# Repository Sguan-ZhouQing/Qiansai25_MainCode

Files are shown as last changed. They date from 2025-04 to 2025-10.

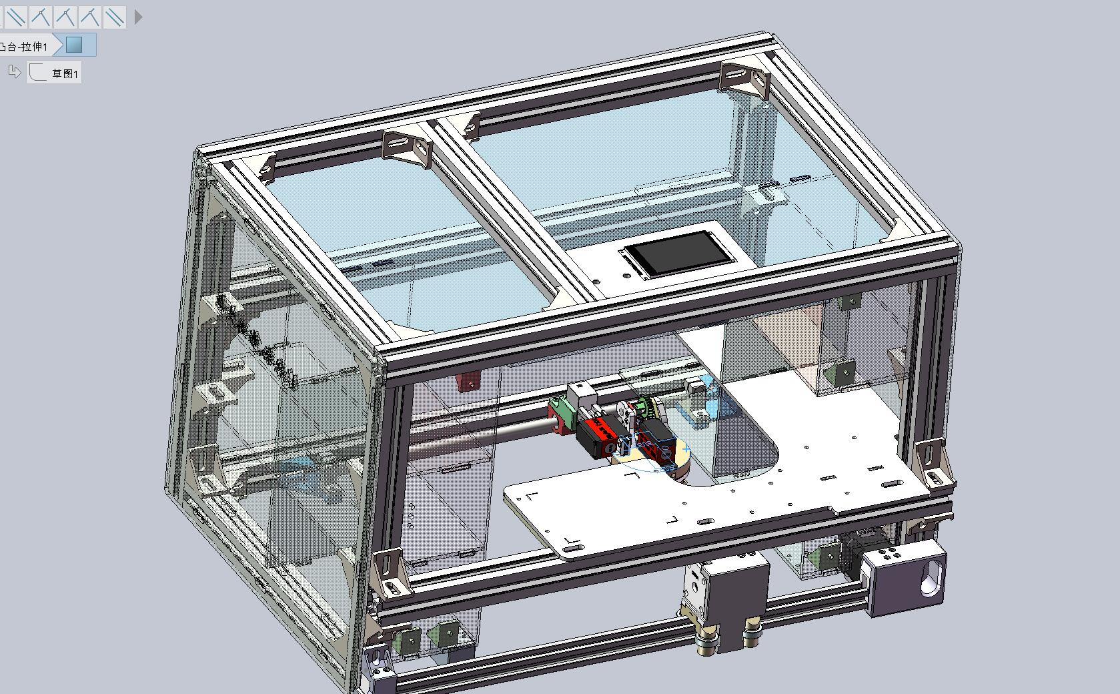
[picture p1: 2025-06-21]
药仓实况照片.jpg

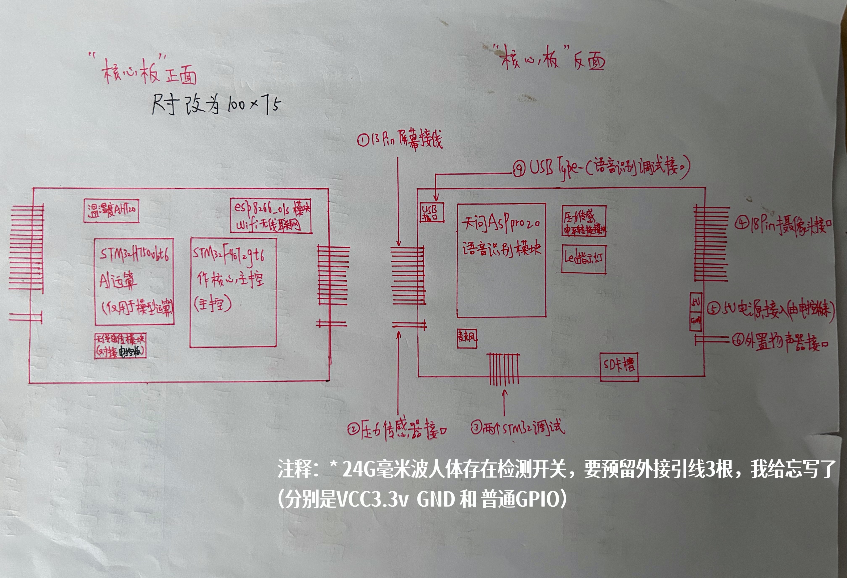
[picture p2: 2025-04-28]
电路篇/核心板PCB大纲.JPG

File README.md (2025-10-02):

# Qiansai25_MainCode
An integrated intelligent pharmacy warehouse that integrates medication management.集用药管理平台的一体化药仓

[![zread](https://img.shields.io/badge/Ask_Zread-_.svg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)](https://zread.ai/Sguan-ZhouQing/Qiansai25_MainCode)
https://zread.ai/Sguan-ZhouQing/Qiansai25_MainCode

QQ截图20250622031556

主控采用STM32F407vgt6，

运算使用STM32H750vbt6，

电控使用的是芯片是STM32G431cbt6！

This project designed an integrated intelligent medicine warehouse for personal home use and hospital commercialization. The main functions of this medicine warehouse include intelligent visual recognition, custom storage and automatic drug pick-up, automatic human body induction switching power supply, adjustable medication and drug pick-up time reminder, independent drug contraindication reminder, medication calendar recording and analysis, cloud platform data storage...... For long-term drug users or those who have more drug storage needs, the use of the integrated medicine warehouse of this project can greatly reduce the time of drug search, and can know the health index of their long-term medication in real time. The main control of the drug warehouse designed in this project uses the STM32H7 series of high-performance microprocessors for the calculation of the "lightweight AI model", and feeds back the analyzed medication information to the main control STM32F407 for processing. The main control is separated from the motor that actually drives the drug dispensing mechanism, and its operation is controlled by wireless transparent transmission. In addition, we have also developed a "embedded GUI interface" and a "mobile phone APP" suitable for the use of medicine warehouses, and we have also developed medicine warehouses to store user data for the cloud platform and share it with other devices.

本项目设计了一款面向个人家用和医院商用的**一体化智能药仓**，旨在通过智能化技术解决药品管理中的痛点问题。系统以STM32H7系列高性能微处理器为核心，搭载轻量化AI视觉识别模型，可自动识别药品的形态、颜色和包装特征，实现药品的智能分类与入库管理。同时，主控STM32F407负责协调药仓的机电控制系统，通过无线透传模块与执行机构通信，实现药品的精准抓取和配送。

药仓配备多模态传感器阵列，包括红外人体感应模块、重量检测单元和环境监测传感器，可智能感知用户接近自动唤醒系统，并实时监控药品存储环境（温湿度、光照等）。创新设计的**服药智能提醒系统**支持自定义服药时间设置，通过语音播报、LED指示灯和手机APP推送三重提醒方式，确保用户按时服药。系统还能基于药品数据库自动分析药物配伍禁忌，在取药时提供安全警示。

为提升用户体验，我们开发了**嵌入式图形化操作界面**，采用触控屏实现交互，支持药品信息查询、服药记录查看等功能。配套的**跨平台手机APP**（支持iOS/Android）允许用户远程管理药仓、设置服药计划，并生成可视化的服药健康报告。所有数据通过MQTT协议同步至OneNET云平台，实现多设备间的数据共享和长期健康趋势分析，为慢性病患者和家庭医生提供决策支持。

在机械结构方面，药仓采用模块化设计，抽屉式药格可根据药品尺寸灵活调整，伺服电机驱动的机械臂配合高精度导轨实现药品的平稳取放。系统还预留了扩展接口，可兼容医院HIS系统或智能家居平台，满足家庭医疗和机构场景的不同需求。通过这一创新设计，我们期望能显著提升长期服药患者的用药依从性，减少人为用药错误，并为智慧医疗和健康管理提供可靠的硬件支持。

This project designs an integrated intelligent medicine warehouse for personal household and hospital commercialization, aiming to solve the pain points in drug management through intelligent technology. The system is based on the STM32H7 series of high-performance microprocessors and is equipped with a lightweight AI visual recognition model, which can automatically identify the shape, color and packaging characteristics of drugs, and realize the intelligent classification and storage management of drugs. At the same time, the main control STM32F407 is responsible for coordinating the electromechanical control system of the medicine warehouse, and communicates with the actuator through the wireless transparent transmission module to achieve accurate grasping and distribution of drugs.

The pharmacy warehouse is equipped with a multi-modal sensor array, including an infrared human body sensing module, a weight detection unit and an environmental monitoring sensor, which can intelligently perceive the automatic wake-up system when the user is approaching, and monitor the drug storage environment (temperature, humidity, light, etc.) in real time. The innovatively designed intelligent medication reminder system supports custom medication time settings, and ensures that users take their medication on time through voice broadcasting, LED indicators and mobile APP push triple reminders. The system can also automatically analyze drug compatibility contraindications based on the drug database, and provide safety warnings when taking drugs.

In order to improve the user experience, we have developed an embedded graphical operation interface, which uses a touch screen to achieve interaction, and supports functions such as drug information query and medication record viewing. The companion cross-platform mobile app (iOS/Android supported) allows users to remotely manage the pharmacy, set up medication schedules, and generate visual medication health reports. All data is synchronized to the OneNET cloud platform through the MQTT protocol to achieve data sharing and long-term health trend analysis between multiple devices, and provide decision-making support for patients with chronic diseases and family doctors.

In terms of mechanical structure, the medicine warehouse adopts a modular design, the drawer-type medicine compartment can be flexibly adjusted according to the size of the drug, and the robotic arm driven by the servo motor cooperates with the high-precision guide rail to achieve smooth access and placement of drugs. The system also reserves an expansion interface, which can be compatible with hospital HIS system or smart home platform to meet the different needs of home medical and institutional scenarios. Through this innovative design, we expect to significantly improve medication compliance for patients taking long-term medications, reduce human medication errors, and provide reliable hardware support for smart healthcare and health management.

集用药管理平台的一体化智能药仓
STorm小分队；周庆；薛琬莹；钱一程；刘勇
摘要	
本作品“集用药管理平台的一体化智能药仓”基于机电一体化硬件、AI中枢与云端协同网络，实现了药品存储、管理与配送的智能化解决方案。系统以STM32H7高性能处理器为核心，搭载轻量化AI视觉识别模型，结合STM32F407主控与STM32G431电控板，通过多模态传感器（红外对射、压力传感器等）实现药品的精准抓取和配送。机械结构采用模块化分隔设计，支持灵活调整以适应医院药房和家庭健康监护场景。
功能上，系统具备实时环境监控、用户接近感知自动唤醒、多模式服药提醒（语音、LED、APP推送）、药品配伍禁忌分析及嵌入式触控交互界面。配套跨平台手机APP（iOS/Android）支持远程管理，数据通过MQTT协议同步至OneNET云平台，实现多设备协同。
技术层面，项目融合Uinapp、FreeRTOS、STM32CubeAI及LVGL图形化GUI，采用多核异构架构与分布式控制，结合无线/有线通信方式，确保高效稳定的运行。简化传统药物存储流程，降低人力成本；通过智能化管理提升用药安全性与便捷性；模块化设计增强系统扩展性。最终成果通过严格的测试验证，满足药物抓取精度、云端部署等性能指标，为医疗健康领域提供了高效、可靠的物联网应用范例。

第一部分  作品概述
1.1	功能与特性
实现药品的精准抓取和配送，实时监控药品存储环境，智能感知用户接近自动唤醒，服药智能提醒系统可自定义服药时间，通过语音播报、LED指示灯和手机APP推送等提醒方式；系统基于药品数据库自动分析药物配伍禁忌，在取药时提供安全警示；嵌入式图形化操作界面采用触控屏实现交互，提升面向对象的使用体验。
1.2	应用领域
本系统为医疗机构和家庭用药场景提供智能化管理解决方案。在医疗领域，系统通过自动化药品抓取配送、配伍禁忌分析和环境监测三大功能，有效解决传统药房人工管理效率低、易出错的问题…可集成至医院智能药房，实现药品的精准分类、库存实时监控及快速取药。智能化的药品分类与库存监控配合云端数据同步，使管理人员可实时掌握药品信息，优化资源配置。
针对家庭用药场景，系统通过多模式提醒、触控交互和近场感应技术，为老年人和慢性病患者提供便捷的用药管理服务。家庭成员可通过专属APP实现远程监护，确保用药安全。系统兼具专业性与易用性，提供无障碍体验,显著提升医疗和家庭场景的用药管理效率。
1.3	主要技术特点
本系统基于Uinapp框架构建跨平台移动应用，实现iOS/Android双端兼容的用户交互界面，通过FreeRTOS实时操作系统对多任务进行高效调度，确保系统响应实时性。利用STM32Cube.AI工具链部署轻量化AI模型至嵌入式端，实现本地化药品识别与配伍分析，显著降低云端依赖。系统采用LVGL图形化GUI框架开发触控交互界面，优化人机交互体验，同时集成Wi-Fi、蓝牙、I2C、SPI、CAN等多种通信方式，构建灵活可靠的数据传输网络，支持设备间协同与云端数据同步。这一技术架构在保证系统实时性能的同时，实现了实时计算到云端协同的完整解决方案。
1.4	主要性能指标
图像识别准确率，IOT联网成功率，机械臂能够稳定抓取药品的容错率。

1.5	主要创新点
1.	解决了传统药物存储和分类的繁琐流程，简化了人力物力支出。方便药品后期管理和实时用药取药，有效解决传统药房人工管理效率低、易出错的问题。
2.	机械结构采用可快速重构的模块化方案，同一平台可适配医院药房和家庭用药两种差异化的应用场景。
3.	创新性地在边缘设备部署轻量化AI模型，同时通过MQTT协议实现云端数据同步，在保证响应速度的同时实现了多终端数据共享。
4.	结合毫米波接近感应和语音交互技术，为老年用户提供了更人性化的无接触操作体验。
1.6	设计流程
 
本项目遵循系统化的设计开发流程，从项目方案的技术定型阶段开始，工程团队首先完成核心机器架构的详细设计，并实现关键支撑结构的组装验证。随后进入硬件工程实施阶段，涵盖机械结构设计、多层PCB电路板的精密印刷与焊接工艺、机电一体化装配，以及严格的电路功能测试和系统安装方案优化。在软件层面，项目团队同步开展模块化驱动开发工作，在完成底层驱动开发后，团队构建了完整的应用层业务逻辑，同时推进云端服务架构设计，采用OneNET云平台在阿里云环境实现高可用部署。项目最终经过严格的系统级测试验证，包括功能测试、性能测试和稳定性测试，确保整体系统达到设计指标。

第二部分  系统组成及功能说明
2.1	整体介绍
 
智能药仓集成机电一体化硬件与AI技术，核心采用STM32系列处理器（H7/F407/G431）协调控制，搭载轻量化AI视觉识别模型和多模态传感器阵列，实现药品精准抓取、环境监测及用户感知。系统支持模块化药仓设计，具备智能服药提醒（语音/LED/APP推送）、药物配伍禁忌警示及触控屏交互功能，配套跨平台APP支持远程管理，通过MQTT协议与云端同步数据，满足医院药房和家庭场景的智能化药品管理需求。
2.2	硬件系统介绍
2.2.1 硬件整体介绍；
本系统以STM32H7高性能处理器作为核心运算单元，运行轻量化AI视觉识别算法实现药品智能识别。系统主控采用STM32F407微控制器，协调药仓机电控制系统，与分布式控制单元（基于STM32G431的电控板）实时交互。各执行器单元集成高精度红外对射传感器和应变式压力传感器，实现药品抓取定位和配送。
2.2.2 机械设计介绍
 机械结构设计采用30-30铝型材搭建药仓整体的骨骼框架，并在多处使用了高透或乳白色亚克力板。整个项目药品的抓取和拿放都依靠其中5个270度舵机组成的简易机械臂和XY轴步进电机驱动系统。项目实物多处使用到了M4和M6公制螺丝进行加固，并在设计到实物的过程中，普遍采用到了3D打印技术去完成本项目的实物制作需求。
	在此一体化智能药仓项目在实物搭建上，使用到了亚克力玻璃板将药仓空间划分为12个单独的储存仓室，并准备为每一个仓室适配各自的夹取药品的机械运动轨迹…实现药物精准配送。
 	 
	对于机械臂的设计，我们使用到了5个20N·cm的270度舵机，并依次连接组合成了一个5个自由度的机械抓取机构。同时，机械臂底部B轴与XY轴步进驱动系统相连，可以让整体机械臂在药仓的运动范围不受太大限制，实现药物配送任务的快速完成。详细到机械臂末端抓取机构，本团队成员使用到了舵机链接“双人字齿轮”，驱动平行对称的连杆机构，进而达到抓取药品有较平稳的夹取姿态。
在机械爪末端预留了槽位用于“红外对射传感器”和“薄膜压力传感器”的安装。它的作用是检测夹取药品时，判断当前位置是否真有药品可以用于夹取，并在夹取过程中通过压力传感器得到力度合适的舵机运动角度。
	 
本项目药仓还在实物顶部设计了“可容纳摄像头模组和触控屏”的非标机械设计，可用于后期做药品的图像采集和图像识别…从而完善整个工程从药品入库到配送这一流程链的智能和自动化的属性。
 
	在亚克力板设计上，项目也有为后期电路PCB板的安装上的思虑。团队成员为所有可能安装电路板和电线走线的地方都有一定安装余留和孔位预留。这为为后期电路搭建建立了良好的容错空间。

2.2.3 电路各模块介绍
 
本项目的电路驱动系统采用到了3块ST公司主流的MCU产品，他们分别是用于主控的STM32F407VGT6，用于做电机控制的STM32G431CBT6和可部署“STM32cube.AI工具链”用于做药仓的药品入库图像识别。其中，用于主控和图像识别的MCU，我们使用到了自绘的“洞洞板”连接各个模块的功能引脚…而对于电机控制的电控板，我们自制了完整的电路开发板，其PCB设计界面及原理图如下：

2.3	软件系统介绍
2.3.1 软件整体介绍（含PC端或云端，结合关键图片）；
软件上本项目采用到了GUI_Guider软件设计LVGL图形化GUI界面，完美适配STM32端单片机的屏幕软件触控交互。团队成员也同时开发了网页端和APP端的上位机控制控制软件，实现药仓万物互联…可以通过分享账号，让家人或者管理人员远程操控药仓的入库及配药。
   
2.3.2 软件各模块介绍
	上位机APP和云端代码由我们团队成员使用Vue.js和HBuilderX自主开发完成。Vue.js是一个用于构建用户界面的渐进式 JavaScript 框架,也是当前的最流行的前端开发框架之一。Vue.js的双向数据绑定机制，很好的支持了我们APP和云端网站的数据动态更新及交互。此外，我们使用HBuilderX将Vue.js代码打包成apk安装包和web包，使Vue.js代码既可在移动端应用，也可在PC端部署，丰富了项目的软件生态。
上位机APP与云端网站通过HTTP请求，以OneNet平台为媒介实现与硬件之间的通信。
 
图为APP读取硬件设备数据

图为APP下发命令控制硬件设备

	 APP主要页面包括：首页（导航页面）、存药页面、取药页面、药仓药品实时情况页面等。登陆页面密码固定为：123456。
 
APP结构图
可视化图表为用户提供清晰明了的药仓数据，其中涉及到的主要代码逻辑为：封装自定义组件CircleChart、从 OneNet平台获取数据、对数据进行处理、使用自定义组件CircleChart进行图表绘制。
用户可通过APP查询药仓实时情况，实现异地查询药仓药品情况，打破空间限制。用户仅需在药仓实时情况页面点击“获取药仓药品信息”按钮，即可获取最新信息。Vue.js的双向数据绑定机制支持动态更新数据，用户可以随时获取最新信息。
  
图为获取最新药品信息操作流程
我们还使用HBuilderX将uniapp项目打包成web代码，并通过宝塔面板将其部署到阿里云服务器上。使用者不仅可以下载APP，还可以通过访问我们的网站来实现对药仓的操控或查询药仓药品。虽然移动端APP使用起来十分便利。但是云端网站仍然具有不占手机内存，不限制手机操作系统（安卓和苹果均可在浏览器输入网址访问我们的网站）等优点。 

第三部分  完成情况及性能参数
阐述最终实现的成果（图文结合，实物照片为主）
3.1	 整体介绍（整个系统实物的正面、斜45°全局性照片）

3.2	 工程成果（分硬件实物、软件界面等设计结果）
3.2.1 机械成果；

3.2.2 电路成果；
  
以上为自制电控板的整体构成，以下为核心板（主控及STM32H750模型运算单元的模块连接电路设计）

3.2.3 软件成果；

（界面照片）
第四部分  总结
4.1	 可扩展之处
智能药仓的AI视觉识别系统可通过持续模型迭代大幅提升功能覆盖范围与精度。在药品识别方面，当前轻量化模型可支持单一药品的快速分类，未来通过引入更复杂的卷积神经网络（如ResNet改进架构）和多模态训练数据（包括药品包装的3D扫描图像、光学字符识别OCR增强的说明书文本），系统可实现对混合摆放药品的同步识别与自动分拣，显著提升药房分拣效率。进一步结合医院的电子处方系统，AI可自动核对处方药品与实际抓取的匹配度，通过比对药品数据库中的剂量、剂型及禁忌症数据，在取药环节即时警示潜在错误（如剂量超标或配伍冲突），形成闭环药品安全校验机制。
在个性化用药管理方面，系统可深度整合用户健康数据流：通过蓝牙/Wi-Fi接入智能手环、血糖仪等IoT设备，实时同步用户的生理指标（如心率、血压、血糖趋势），结合药品药效动力学模型，动态调整服药提醒策略。例如，检测到用户血压异常时，自动延迟服用降压药并推送医生咨询建议；或根据睡眠监测数据优化镇静类药物的分发时间。AI引擎还可学习用户的历史用药记录与反馈，生成用药效果评估报告，为家庭医生提供调整用药方案的参考依据。这种数据驱动的个性化服务，既能提升用药依从性，又能降低不良反应风险，实现从“被动提醒”到“主动健康干预”的升级。

4.2	心得体会
参与 “一体化智能药仓” 项目的开发，是一次将嵌入式技术、人工智能与医疗需求深度融合的实践旅程。从最初的政策解读到最终的软硬件协同运行，每一步都充满挑战，却也让我们深刻体会到 “用技术解决实际问题” 的成就感。

项目启动时，我们反复研读《“十四五” 全民健康信息化规划》中 “药品精细化管理” 的要求。这些要求让我们坚定了方向：要做一个真正 “有用” 的智能药仓，而不只是堆砌技术的展示品。

硬件开发的过程，更像一场与 “稳定性” 的博弈。机械臂的设计曾让我们纠结许久，最初为了追求速度，选用了高扭矩舵机，却发现抓取药品时容易打滑。后来在机械爪内侧增加了硅胶垫，又通过压力传感器反复测试力度 —— 这个看似简单的调整，背后是团队连续一周的调试，只为让每一次取药都稳当可靠。记得第一次看到机械臂稳稳抓起感冒灵颗粒，精准放进指定仓位时，大家都忘了疲惫，因为这意味着我们离 “减少错服风险” 的目标近了一步。

在调试软硬件交互时，我们发现无论使用APP发送多少次HTTP请求，硬件方面都未执行对应操作。我们排查了每一处技术细节，反复检验代码逻辑，在使用“Vofa串口通信”软件检查ESP8266时，发现ESP8266能正常收到信息。于是我们猜测可能是我们将ESP8266与STM32F407之间的串口连接错误了。通过检查串口连接，果然发现了错误，重新连接后，硬件端可以成功执行软件发送的指令，软硬件交互成功了！这一刻，团队付出的所有努力都有了意义。

AI 视觉识别模块的开发，让药仓有了 “看懂” 药品的能力。我们没有追求复杂的模型，而是聚焦实用性：用轻量化算法实现快速识别，确保老人存药时不用等待太久。当系统第一次准确识别出 “复方感冒灵片” 并自动关联效期提醒时，我突然意识到，技术的温度就藏在这些贴心的细节里 —— 它能让独居老人不用再对着药盒发愁，让忙碌的药师少一份核对的压力。

在上位机 APP 的开发与设计中，则教会我们要多尝试新方法。最初页面功能繁杂，开发时任务艰巨，仅在HBuilderX的内置浏览器中测试软件功能。后续将代码打包成APK安装包后进入手机实测，发现APP“存药”无法触发。为了解决这个问题，我们团队成员先打开手机的开发者模式和无线调试，将手机连接HBuilderX进行调试，反复阅读代码，并在一些可能出错的地方进行修改，积极进行尝试，虽然每一次尝试都已失败告终，但是我们告诉自己，每一次失败都排除了一种错误方法。最终定位错误为Vue中select组件与安卓系统不兼容，于是我们尝试更换了picker组件并解决了问题。

回望整个过程，技术只是手段，解决问题才是目的。智能药仓的每一个零件、每一行代码，最终都指向同一个目标：让药品管理更安全、更简单。这段经历让我明白，真正有价值的创新，从来不是炫技式的突破，而是像春雨般润物无声 —— 用技术的力量，悄悄解决那些被忽视的民生痛点，让生活多一份安心与便利。这或许就是我们作为开发者，最该坚守的初心。

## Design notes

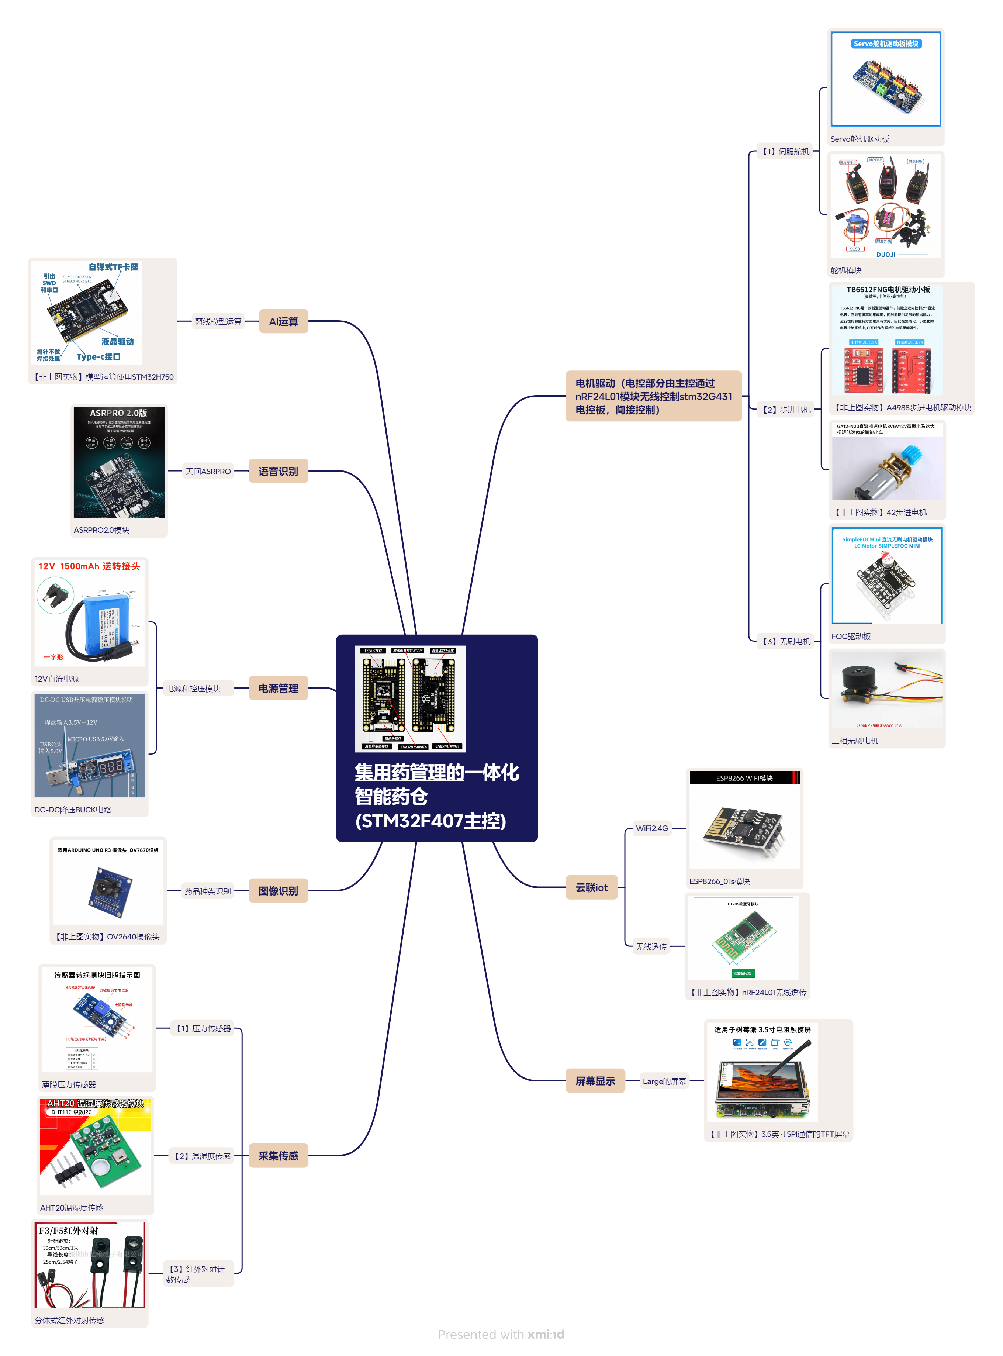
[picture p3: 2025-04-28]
嵌赛25大纲.png

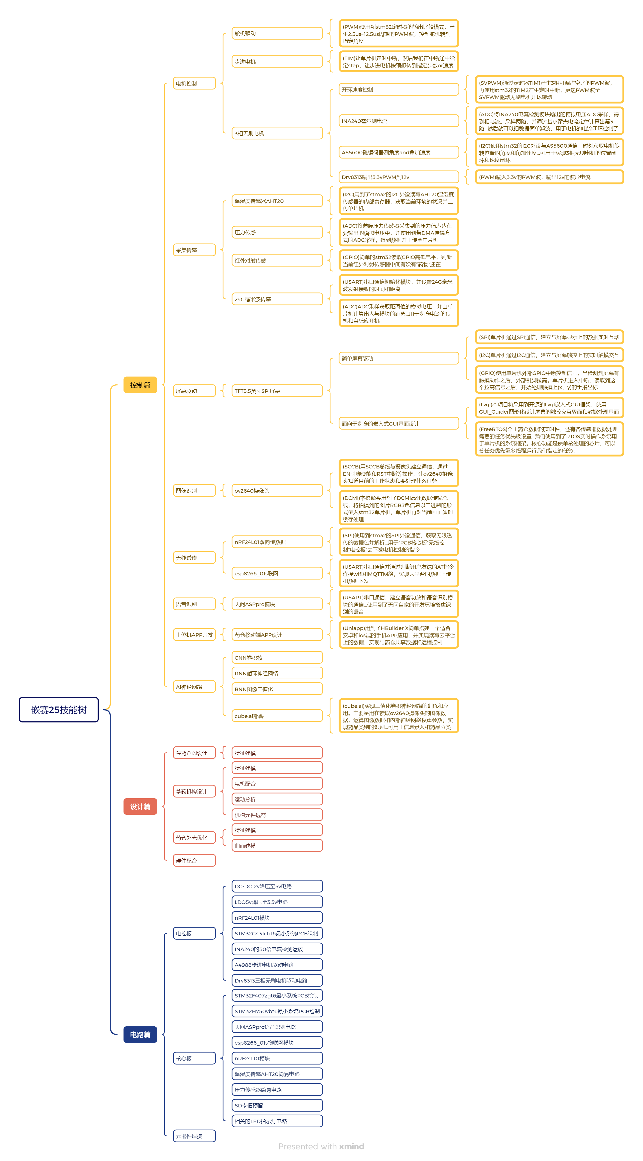
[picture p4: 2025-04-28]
嵌赛25技能树.png

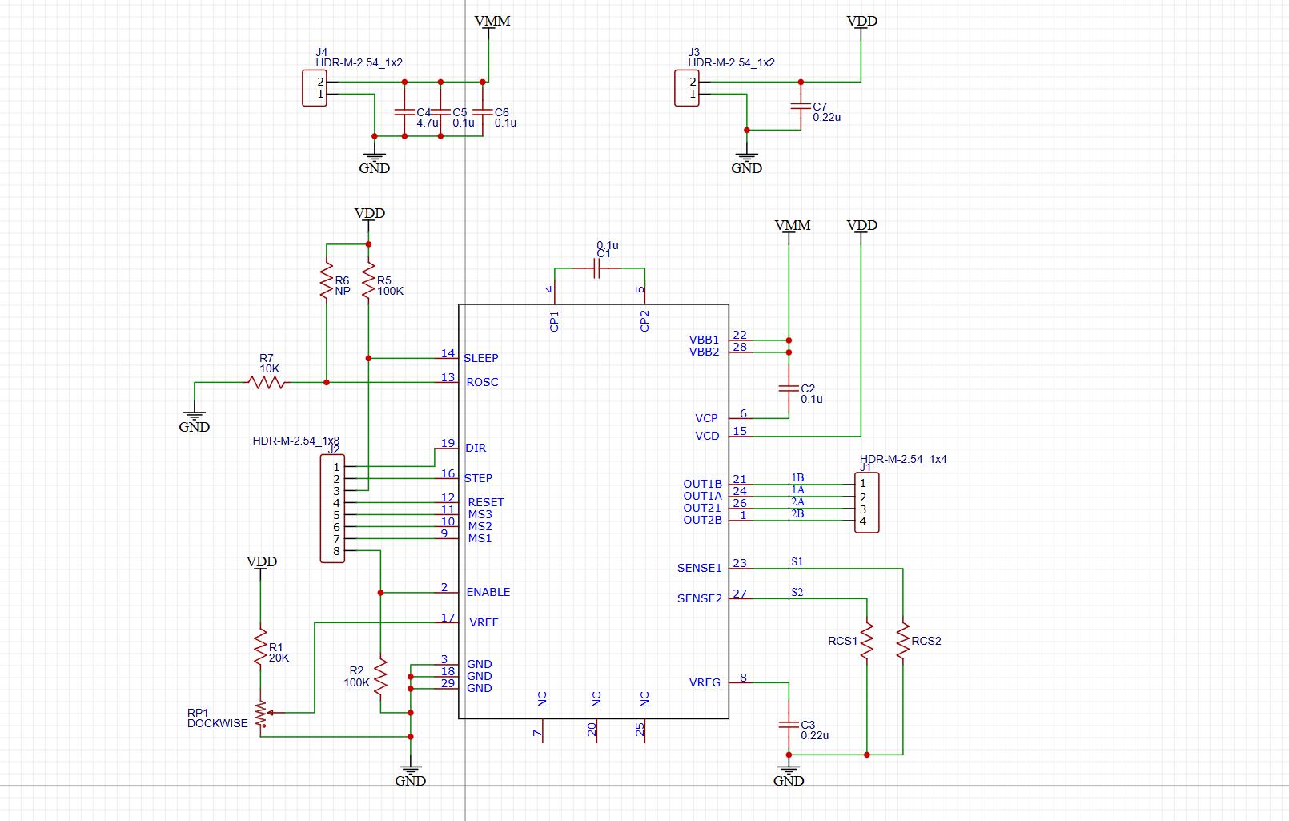
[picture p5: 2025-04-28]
电路篇/电控板（100x90尺寸）/A4988步进电机驱动.jpg

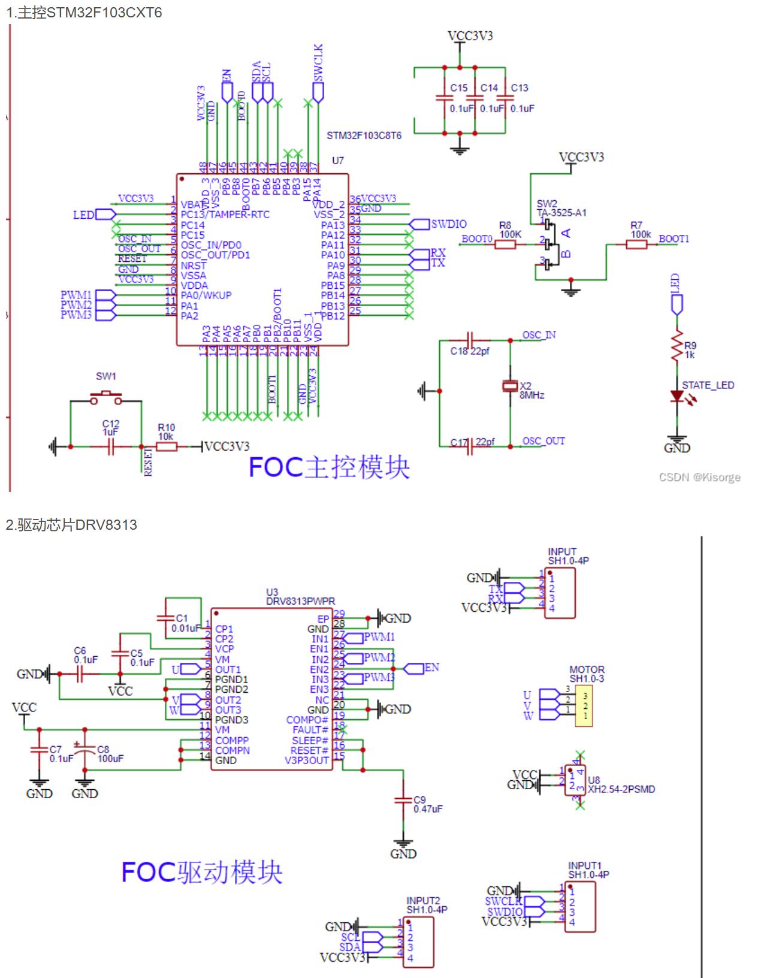
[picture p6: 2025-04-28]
电路篇/电控板（100x90尺寸）/可借鉴的SimpleFOC电路.jpg

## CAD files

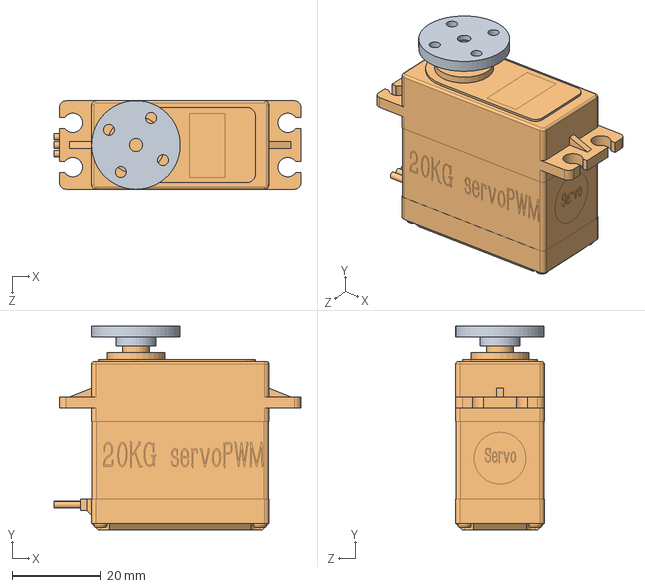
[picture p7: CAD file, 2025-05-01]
设计篇/【15】270度大舵机(配合体整体).SLDASM
55.8 x 46.0 x 20.0 mm
【15】270度大舵机(定子)
【15】270度大舵机(转子)

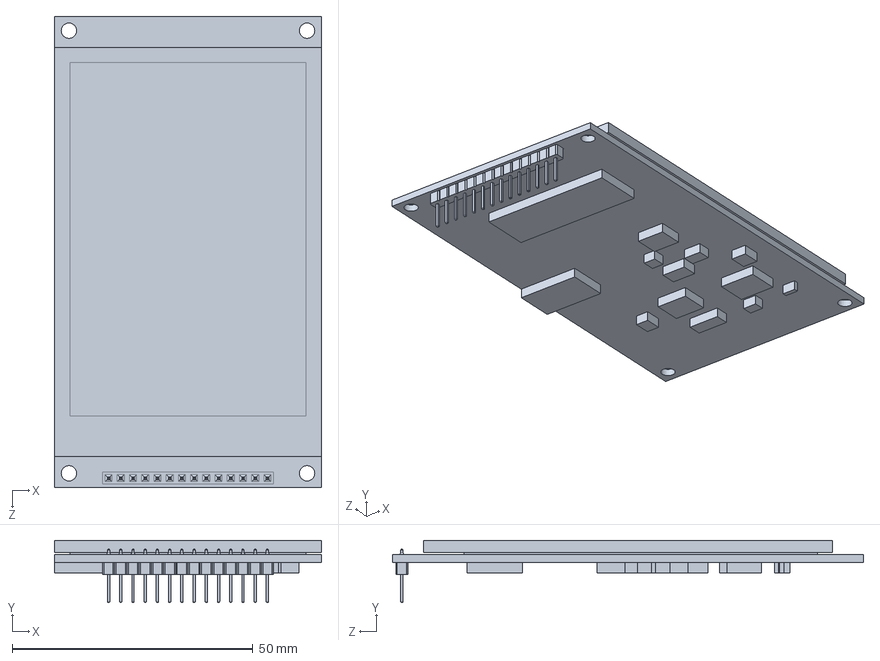
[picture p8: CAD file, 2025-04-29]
设计篇/【6】药仓main核心显示屏.SLDPRT
55.5 x 13.0 x 98.0 mm

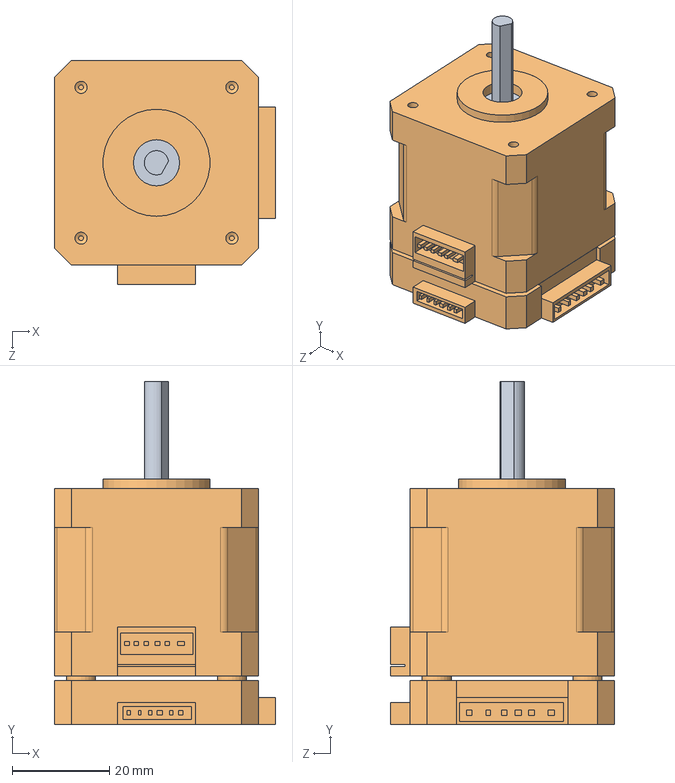
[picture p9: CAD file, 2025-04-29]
设计篇/【4】长型42步进电机(配合体整体).SLDASM
45.5 x 70.5 x 46.0 mm
【4】长型42步进电机(定子)
【4】长型42步进电机(转子)

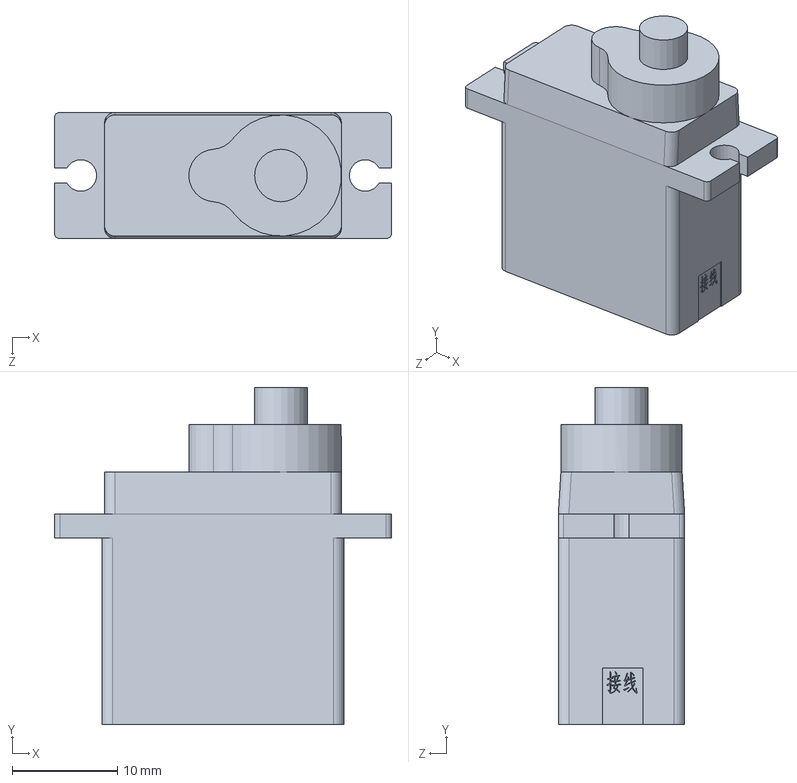
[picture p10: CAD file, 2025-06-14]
设计篇/【10】SG90舵机(定子).SLDPRT
32.0 x 32.0 x 12.0 mm

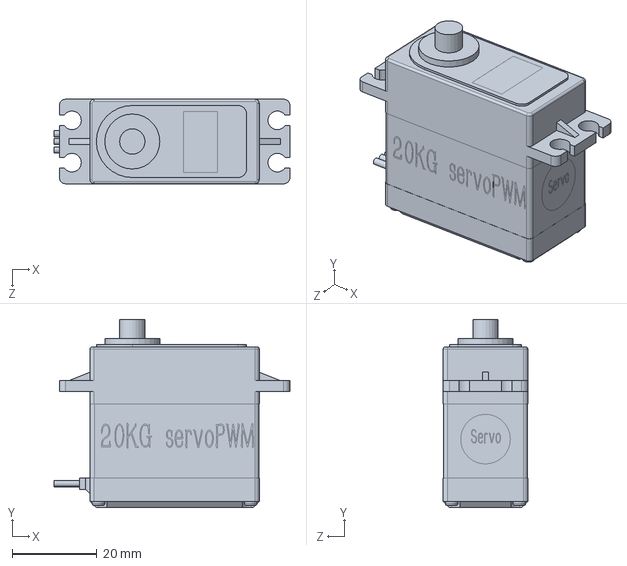
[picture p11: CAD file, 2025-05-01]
设计篇/【15】270度大舵机(定子).SLDPRT
55.8 x 44.5 x 20.0 mm

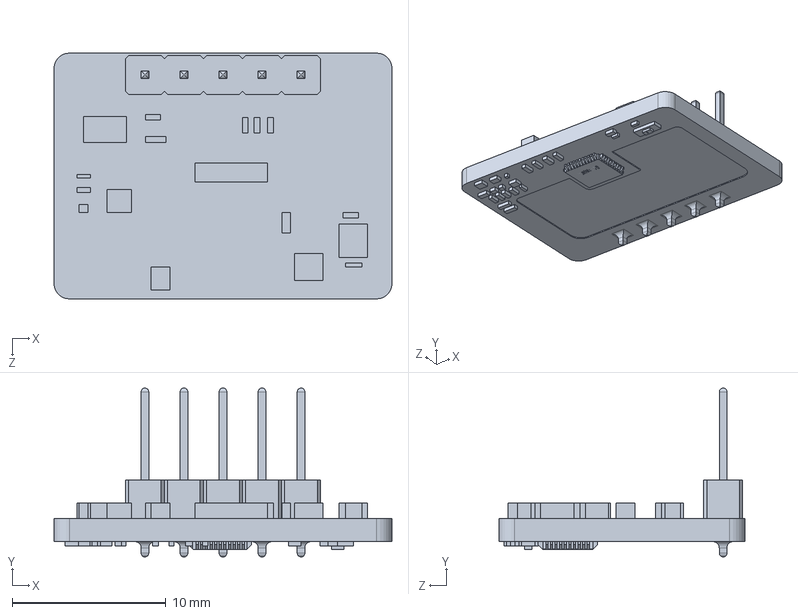
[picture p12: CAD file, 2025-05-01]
设计篇/【13】24G毫米波人体检测模块.SLDPRT
22.0 x 11.0 x 16.0 mm

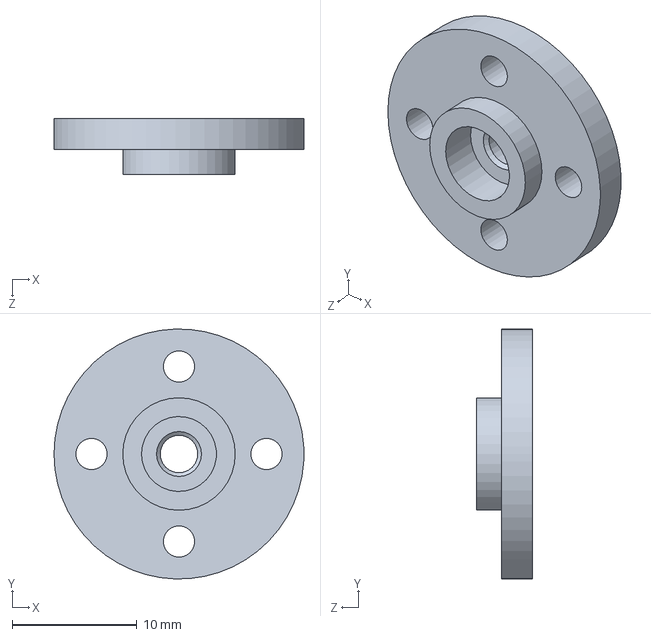
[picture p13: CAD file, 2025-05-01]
设计篇/【15】270度大舵机(转子).SLDPRT
20.0 x 20.0 x 4.50 mm

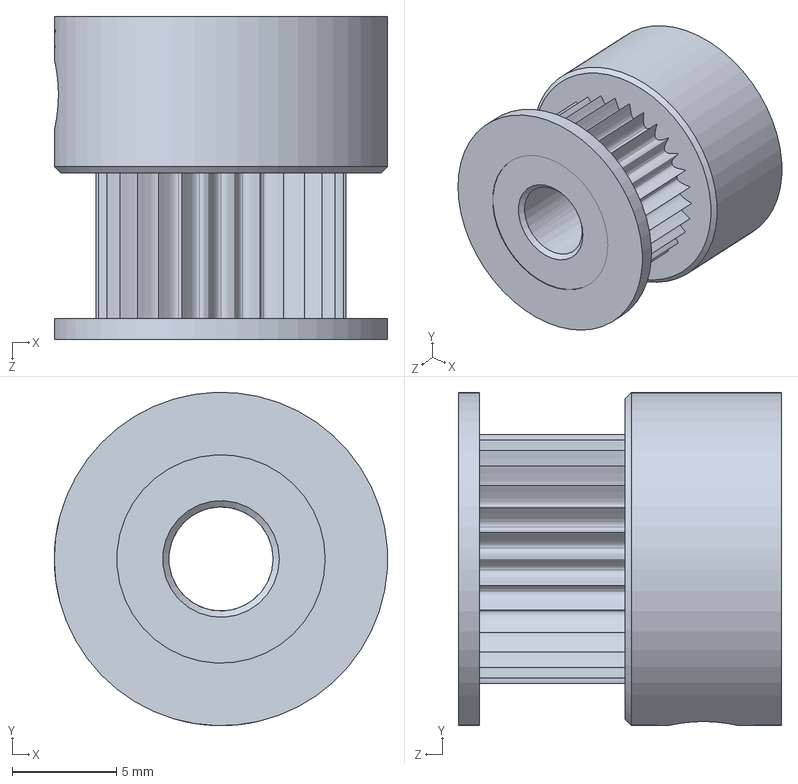
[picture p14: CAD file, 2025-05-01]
设计篇/【14】步进电机传动件.SLDPRT
16.0 x 16.0 x 15.5 mm

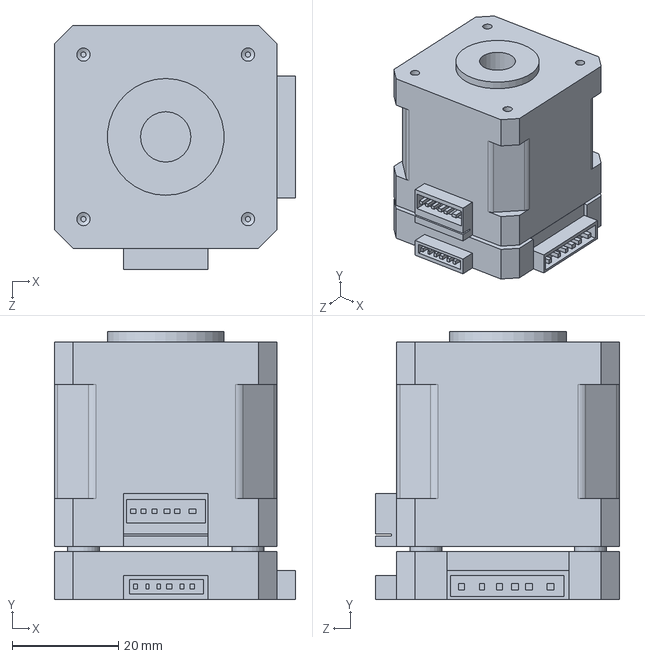
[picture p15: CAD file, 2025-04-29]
设计篇/【4】长型42步进电机(定子).SLDPRT
45.5 x 50.5 x 46.0 mm

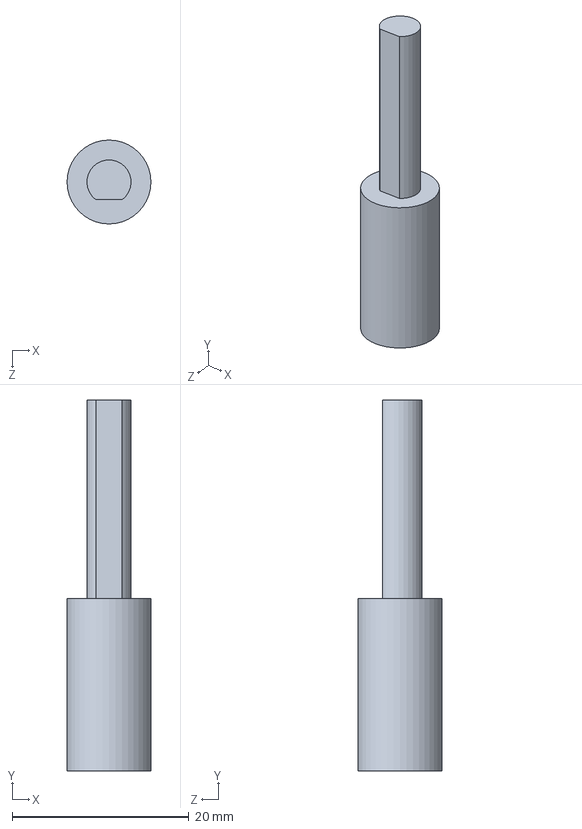
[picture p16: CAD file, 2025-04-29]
设计篇/【4】长型42步进电机(转子).SLDPRT
9.50 x 42.0 x 9.50 mm

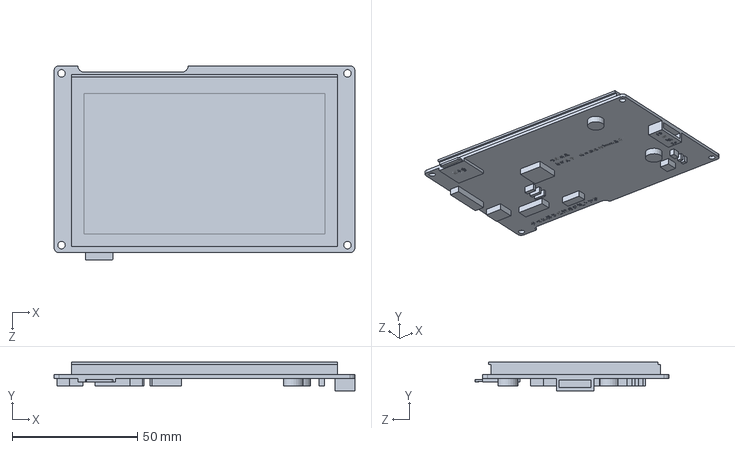
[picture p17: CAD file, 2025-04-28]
设计篇/【8】药仓显示屏.SLDPRT
120.0 x 11.5 x 77.5 mm

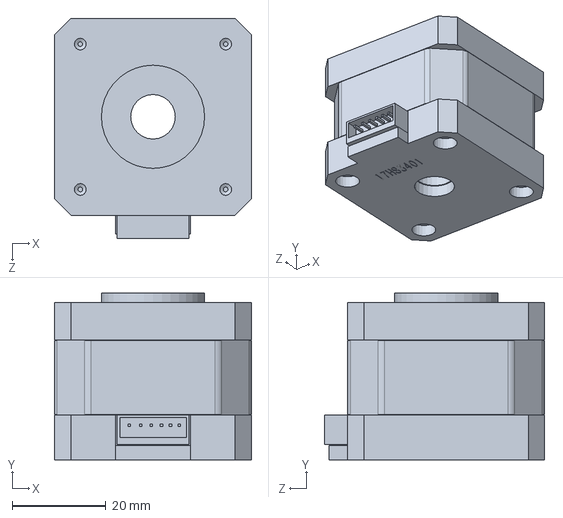
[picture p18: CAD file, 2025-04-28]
设计篇/【2】小型42步进电机(定子).SLDPRT
42.0 x 35.5 x 47.0 mm

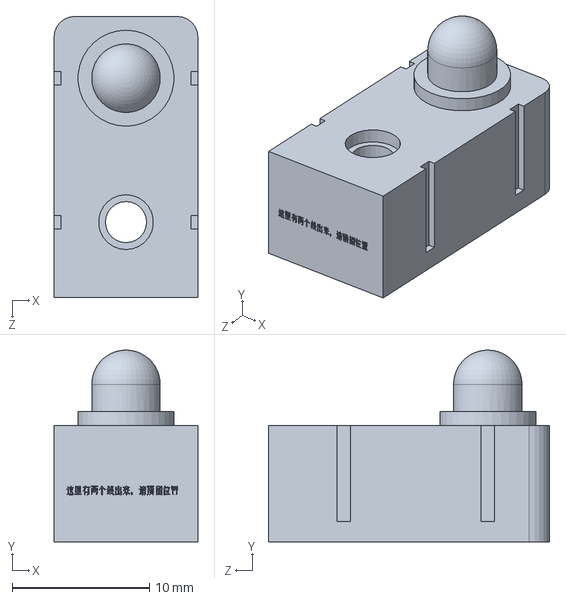
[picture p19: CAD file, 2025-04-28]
设计篇/【3】红外对射传感器(发送，接收共2个).SLDPRT
10.5 x 14.0 x 20.5 mm

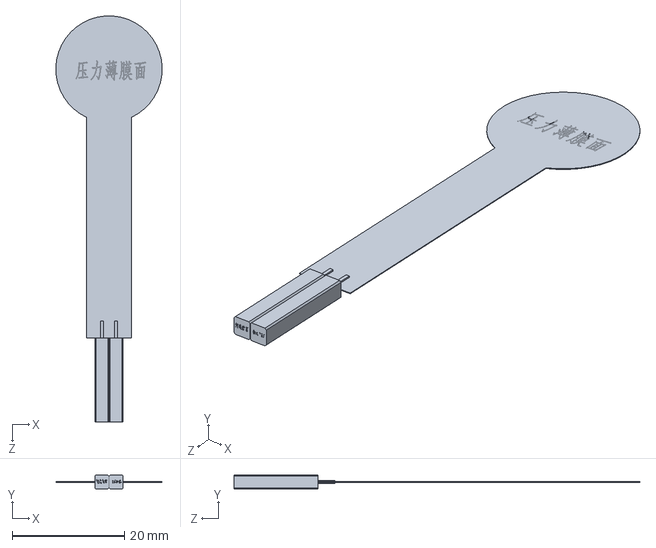
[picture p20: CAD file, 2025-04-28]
设计篇/【7】薄膜压力传感器.SLDPRT
19.0 x 2.54 x 72.5 mm

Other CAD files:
设计篇/【10】SG90舵机(配合体整体).SLDASM
设计篇/【5】三相无刷电机(配合体整体).SLDASM
设计篇/【2】小型42步进电机(配合体整体).SLDASM
设计篇/【5】三相无刷电机(转子).SLDPRT
设计篇/【10】SG90舵机(连接件).SLDPRT
设计篇/【11】电控板.SLDPRT
设计篇/【12】核心板.SLDPRT
设计篇/【1】音响语音播报.SLDPRT
设计篇/【2】小型42步进电机(转子).SLDPRT
设计篇/【5】三相无刷电机(定子).SLDPRT
设计篇/【9】ov2640摄像头.SLDPRT

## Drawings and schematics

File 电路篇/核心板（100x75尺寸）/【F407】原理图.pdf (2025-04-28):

VDD_1 72 PB12 73 PB13 74 PB14 75 PB15 76 PD8 77 PD9 78 PD10 79 PD11 80 PD12 81 PD13 82 VSS_8 83 VDD_8 84 PD14 85 PD15 86 PG2 87 PG3 88 PG4 89 PG5 90 PG6 91 PG7 92 PG8 93 VSS_9 94 VDD_9 95 PC6 96 PC7 97 PC8 98 PC9 99 PA8 100 PA9 101 PA10 102 PA11 103 PA12 104 PA13 105 NC 106 VSS_2 107 VDD_2 108 PA14 109 PA15 110 PC10 111 PC11 112 PC12 113 PD0 114 PD1 115 PD2 116 PD3 117 PD4 118 PD5 119 VSS_10 120 VDD_10 121 PD6 122 PD7 123 PG9 124 PG10 125 PG11 126 PG12 127 PG13 128 PG14 129 VSS_11 130 VDD_11 131 PG15 132 PB3 133 PB4 134 PB5 135 PB6 136 PB7 137 BOOT0 138 PB8 139 PB9 140 PE0 141 PE1 142 VSS_3 143 VDD_3 144

# RTC时钟晶振

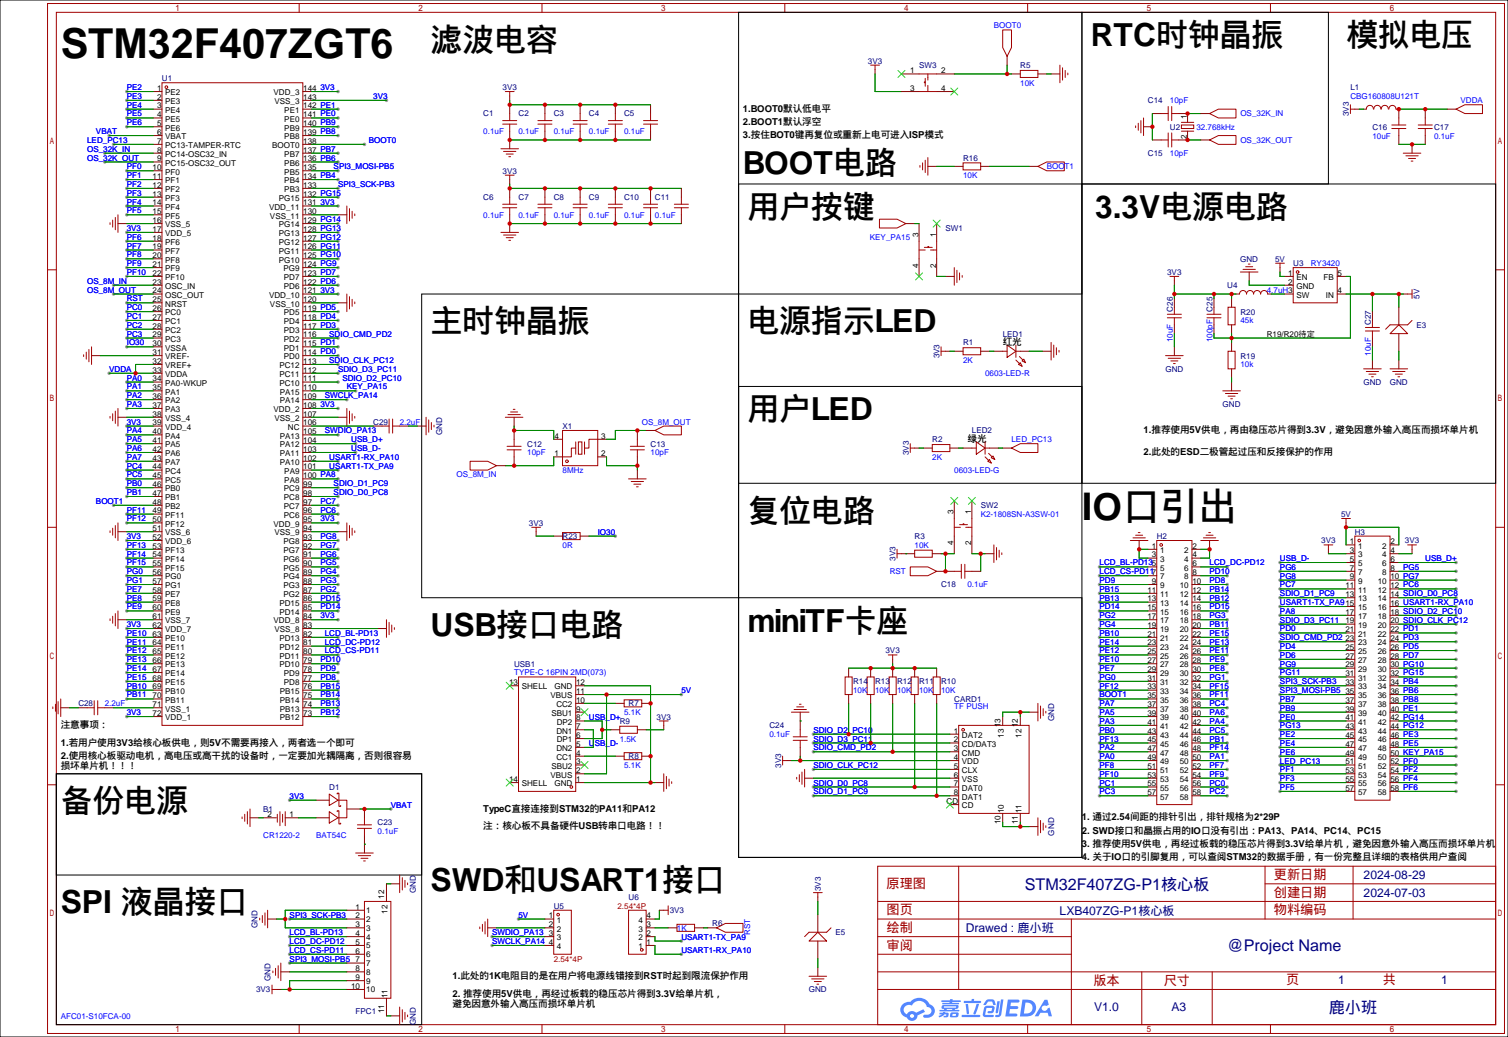
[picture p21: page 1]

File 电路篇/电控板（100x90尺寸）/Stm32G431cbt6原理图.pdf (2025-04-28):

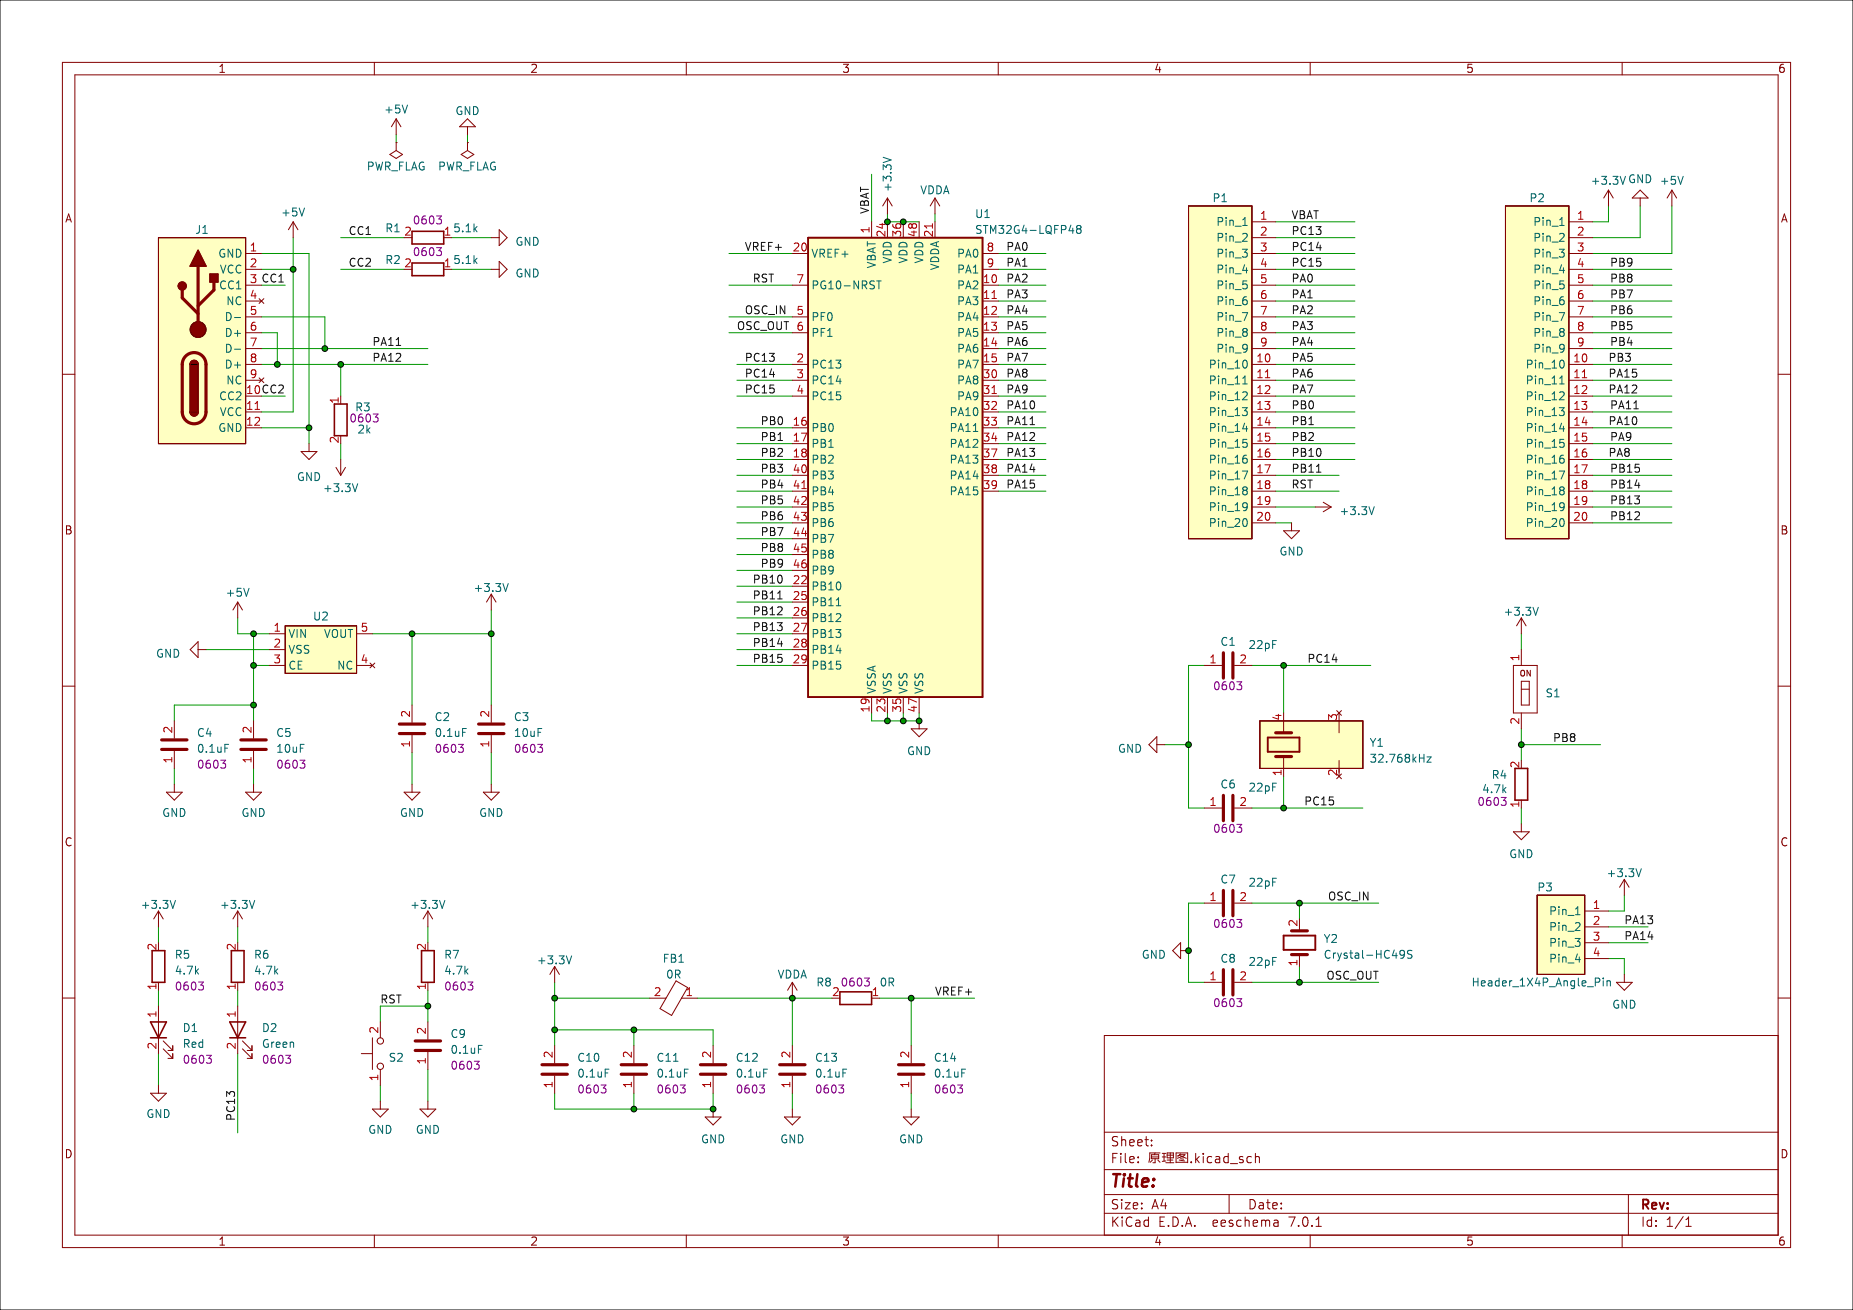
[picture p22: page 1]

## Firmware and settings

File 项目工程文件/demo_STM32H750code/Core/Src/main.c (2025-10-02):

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
/* Includes ------------------------------------------------------------------*/
#include "main.h"
#include "dcmi.h"
#include "dma.h"
#include "fatfs.h"
#include "fdcan.h"
#include "i2c.h"
#include "memorymap.h"
#include "sdmmc.h"
#include "spi.h"
#include "usart.h"
#include "gpio.h"

/* USER CODE BEGIN Includes */
#include <string.h>
#include <stdio.h>
#include "OLED.h"
#include "lcd_spi_154.h"
#include "dcmi_ov2640.h"
#include "sccb.h"
#include "save.h"
#include "CAN_own.h"

/* USER CODE END Includes */


void SystemClock_Config(void);
static void MPU_Config(void);
/* USER CODE BEGIN 0 */

const uint8_t logo_main[] = {
        0x00,0x00,0x00,0x00,0x00,0x00,0x00,0x00,0x00,0x00,0x00,0x00,0x00,0x00,0x00,0x00,0x00,0x00,0x00,0x00,0x00,0x00,0x00,0x00,0x00,0x00,0x00,0x00,0x00,0x00,0x00,0x00,0x00,0x00,0x00,0x00,0x00,0x00,0x00,0x00,
        0x00,0x00,0x00,0x00,0x00,0x00,0x00,0x00,0x00,0x00,0x00,0x00,0x00,0x00,0x00,0x00,0x00,0x00,0x00,0x00,0x00,0x00,0x00,0x00,0x00,0x00,0x00,0x00,0x00,0x00,0x00,0x00,0x00,0x00,0x00,0x00,0x00,0x00,0x00,0x00,
        0x00,0x00,0x00,0x00,0x00,0x00,0x00,0x00,0x00,0x00,0x00,0x00,0x00,0x00,0x00,0x00,0x00,0x00,0x00,0x00,0x00,0x00,0x00,0x00,0x00,0x00,0x00,0x00,0x00,0x00,0x00,0x00,0x00,0x00,0x00,0x00,0x00,0x00,0x00,0x00,
        0x00,0x00,0x00,0x00,0x00,0x00,0x00,0x00,0x00,0x00,0x00,0x00,0x00,0x00,0x00,0x00,0x80,0x80,0x80,0x80,0xC0,0x20,0x20,0x20,0x20,0x3E,0x20,0x20,0x3E,0x20,0x20,0x3E,0x20,0x20,0x3E,0x20,0xE0,0x80,0x80,0x80,0x80,0x00,0x00,0x00,0x60,0x60,
        0x70,0x60,0x60,0x60,0x70,0x60,0x60,0x00,0x00,0x00,0xE0,0x00,0x00,0xE0,0x00,0x00,0xE0,0x00,0x00,0x20,0x20,0x00,0x20,0x20,0xE0,0x20,0x20,0x20,0x00,0xA0,0x20,0x80,0xC0,0xA0,0xA0,0xA0,0xE0,0xC0,0x00,0x00,
        0x00,0x00,0x00,0x80,0xC0,0x20,0x80,0x60,0x40,0x40,0x40,0xC0,0xC0,0x00,0xE0,0x40,0x40,0xE0,0x20,0x20,0x20,0xA0,0xE0,0x00,0x00,0x00,0x80,0xE0,0x20,0x60,0xE0,0x00,0x00,0x00,
        0x00,0xE0,0x00,0x00,0x00,0x00,0xE0,0x00,0x00,0x00,0x00,0x00,0x00,0x00,0x00,0x00,0x00,0x00,0x00,0x00,0x00,0x00,0x00,0x00,0x24,0x24,0x24,0x24,0xFF,0x00,0x00,0xEC,0xBE,0x12,0xBE,0xEC,0x20,0xF0,0x20,0xF8,
        0x20,0xE0,0x00,0x00,0xFF,0x24,0x24,0x24,0x24,0x00,0x00,0x00,0x30,0x0F,0x00,0x3F,0x20,0x2F,0x20,0x27,0x38,0x03,0x00,0x20,0x23,0x10,0x0C,0x0F,0x18,0x20,0x23,0x20,0x00,0x01,0x3F,0x00,0x3F,0x20,0x3F,0x22,
        0x22,0x22,0x00,0x21,0x3F,0x32,0x26,0x32,0x3F,0x22,0x22,0x3E,0x00,0x00,0x50,0x30,0x00,0x00,0x3F,0x00,0x30,0x0E,0x20,0x3F,0x00,0x1E,0x20,0x00,0x27,0x38,0x38,0x27,0x01,0x21,0x21,0x3F,0x01,0x00,0x20,0x3C,
        0x0F,0x0C,0x0C,0x0C,0x0F,0x3F,0x30,0x00,0x00,0x3F,0x00,0x00,0x00,0x00,0x2F,0x00,0x00,0x00,0x00,0x00,0x00,0x00,0x00,0x00,0x00,0x00,0x00,0x00,0x00,0x00,0x00,0x00,0x01,0x01,0x01,0x01,0x0F,0x10,0x10,0x10,
        0x11,0xF1,0x11,0x10,0xF0,0x10,0x10,0xF0,0x10,0x10,0xF0,0x10,0x1F,0x01,0x01,0x01,0x01,0x00,0x00,0x00,0x31,0x29,0x26,0x00,0x00,0x00,0x00,0x0C,0x13,0x11,0x11,0x0E,0x00,0x00,0x00,0x00,0x21,0x31,0x29,0x26,
        0x00,0x00,0x00,0x00,0x00,0x37,0x25,0x3D,0x00,0x00,0x00,0x00,0x00,0x00,0x3D,0x0C,0x05,0x12,0x11,0x00,0x00,0x00,0x00,0x00,0x00,0x00,0x11,0x06,0x04,0x10,0x00,0x00,0x00,0x00,0x00,0x00,0x06,0x1E,0x16,0x07,
        0x03,0x12,0x00,0x00,0x00,0x00,0x00,0x00,0x10,0x08,0x0C,0x10,0x20,0x00,0x00,0x00,0x00,0x00,0x04,0x1D,0x0D,0x1D,0x1D,0x0D,0x00,0x00,0x00,0x00,0x00,0x00,0x00,0x00,0x00,0x00,0x00,0x00,0x00,0x00,0x00,0x00,
        0x00,0x00,0x00,0x00,0x00,0x00,0x00,0x00,0x00,0x03,0x00,0x00,0x03,0x00,0x00,0x03,0x00,0x00,0x03,0x00,0x00,0x00,0x00,0x00,0x00,0x00,0x00,0x00,0x00,0x00,0x00,0x00,0x00,0x00,0x00,0x00,0x00,0x00,0x00,0x00,
        0x00,0x00,0x00,0x00,0x00,0x00,0x00,0x00,0x00,0x00,0x00,0x00,0x00,0x00,0x00,0x00,0x00,0x00,0x00,0x00,0x00,0x00,0x00,0x00,0x00,0x00,0x00,0x00,0x00,0x00,0x00,0x00,0x00,0x00,0x00,0x00,0x00,0x00,0x00,0x00,
        0x00,0x00,0x00,0x00,0x00,0x00,0x00,0x00,0x00,0x00,0x00,0x00,0x00,0x00,0x00,0x00,0x00,0x00,0x00,0x00,0x00,0x00,0x00,0x00,0x00,0x00,0x00,0x00,0x00,0x00,0x00,0x00,0x00,0x00,0x00,0x00,0x00,0x00,0x00,0x00,
        0x00,0x00,0x00,0x00,0x00,0x00,0x00,0x00,0x00,0x00,0x00,0x00,0x00,0x00,0x00,0x00,0x00,0x00,0x00,0x00,0x00,0x00,0x00,0x00,0x00,0x00,0x00,0x00,0x00,0x00,0x00,0x00,0x00,0x00,0x00,0x00,0x00,0x00,0x00,0x00,
        0x00,0x00,0x00,0x00,0x00,0x00,0x00,0x00,0x00,0x00,0x00,0x00,0x00,0x00,0x00,0x00,0x00,0x00,0x00,0x00,0x00,0x00,0x00,0x00,0x00,0x00,0x00,0x00,0x00,0x00,0x00,0x00,0x00,0x00,0x00,0x00,0x00,0x00,0x00,0x00,
        0x00,0x00,0x00,0x00,0x00,0x00,0x00,0x00,0x00,0x00,0x00,0x00,0x00,0x00,0x00,0x00,0x00,0x00,0x00,0x00,0x00,0x00,0x00,0x00,0x00,0x00,0x00,0x00,0x00,0x00,0x00,0x00,0x00,0x00,0x00,0x00,0x00,0x00,0x00,0x00,
        0x00,0x00,0x00,0x00,0x00,0x00,0x00,0x00}; // “芯火征途，你好AI”logo

uint8_t F407_readBuffer[10];        
/* USER CODE END 0 */

/**
  * @brief  The application entry point.
  * @retval int
  */
int main(void)
{

  /* MPU Configuration--------------------------------------------------------*/
  MPU_Config();

  /* MCU Configuration--------------------------------------------------------*/

  /* Reset of all peripherals, Initializes the Flash interface and the Systick. */
  HAL_Init();

  /* USER CODE BEGIN Init */
  SCB_EnableICache();
	SCB_EnableDCache();
  /* USER CODE END Init */

  /* Configure the system clock */
  SystemClock_Config();

  /* Initialize all configured peripherals */
  MX_GPIO_Init();
  MX_DMA_Init();
  MX_I2C2_Init();
  MX_DCMI_Init();
  MX_SPI4_Init();
  MX_USART1_UART_Init();
  MX_SDMMC1_SD_Init();
  MX_FATFS_Init();
  MX_FDCAN1_Init();
  /* USER CODE BEGIN 2 */
  HAL_UARTEx_ReceiveToIdle_DMA(&huart1, F407_readBuffer, sizeof(F407_readBuffer));
  __HAL_DMA_DISABLE_IT(huart1.hdmarx, DMA_IT_HT);
  CAN_ReceptionInit();
  OLED_Init();
  SPI_LCD_Init(); 
	DCMI_OV2640_Init();
	OV2640_DMA_Transmit_Continuous(Camera_Buffer, OV2640_BufferSize);
  f_mkdir("IMG");
  /* USER CODE END 2 */

  /* Infinite loop */
  /* USER CODE BEGIN WHILE */
  while (1)
  {
    OLED_ShowString(0,0,"Init Success!",OLED_8X16);
    // OLED_ShowImage(0,21,128,43,logo_main);
    HAL_GPIO_TogglePin(GPIOC,GPIO_PIN_13);
    /* USER CODE END WHILE */

    /* USER CODE BEGIN 3 */
    if(DCMI_FrameState == 1)
    {
      DCMI_FrameState = 0;
      LCD_CopyBuffer(0, 0, Display_Width, Display_Height, (uint16_t*)Camera_Buffer);
    }
    OLED_Update();
  }
  /* USER CODE END 3 */
}

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
 /* MPU Configuration */

void MPU_Config(void)
{
  MPU_Region_InitTypeDef MPU_InitStruct = {0};

  /* Disables the MPU */
  HAL_MPU_Disable();

  /** Initializes and configures the Region and the memory to be protected
  */
  MPU_InitStruct.Enable = MPU_REGION_ENABLE;
  MPU_InitStruct.Number = MPU_REGION_NUMBER0;
  MPU_InitStruct.BaseAddress = 0x24000000;
  MPU_InitStruct.Size = MPU_REGION_SIZE_512KB;
  MPU_InitStruct.SubRegionDisable = 0x00;
  MPU_InitStruct.TypeExtField = MPU_TEX_LEVEL0;
  MPU_InitStruct.AccessPermission = MPU_REGION_FULL_ACCESS;
  MPU_InitStruct.DisableExec = MPU_INSTRUCTION_ACCESS_ENABLE;
  MPU_InitStruct.IsShareable = MPU_ACCESS_SHAREABLE;
  MPU_InitStruct.IsCacheable = MPU_ACCESS_CACHEABLE;
  MPU_InitStruct.IsBufferable = MPU_ACCESS_BUFFERABLE;

  HAL_MPU_ConfigRegion(&MPU_InitStruct);
  /* Enables the MPU */
  HAL_MPU_Enable(MPU_PRIVILEGED_DEFAULT);

}

/**
  * @brief  This function is executed in case of error occurrence.
  * @retval None
  */
void Error_Handler(void)
{
  /* USER CODE BEGIN Error_Handler_Debug */
  /* User can add his own implementation to report the HAL error return state */
  __disable_irq();
  while (1)
  {
  }
  /* USER CODE END Error_Handler_Debug */
}

#ifdef  USE_FULL_ASSERT
/**
  * @brief  Reports the name of the source file and the source line number
  *         where the assert_param error has occurred.
  * @param  file: pointer to the source file name
  * @param  line: assert_param error line source number
  * @retval None
  */
void assert_failed(uint8_t *file, uint32_t line)
{
  /* USER CODE BEGIN 6 */
  /* User can add his own implementation to report the file name and line number,
     ex: printf("Wrong parameters value: file %s on line %d\r\n", file, line) */
  /* USER CODE END 6 */
}
#endif /* USE_FULL_ASSERT */

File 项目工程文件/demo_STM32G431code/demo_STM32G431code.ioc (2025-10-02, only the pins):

Mcu.UserName=STM32G431CBTx
PA12.GPIO_Label=CE
PA12.Signal=GPIO_Output
PA13.Signal=SYS_JTMS-SWDIO
PA14.Signal=SYS_JTCK-SWCLK
PA15.Signal=I2C1_SCL
PA6.GPIO_Label=DIR1
PA6.Signal=GPIO_Output
PA7.GPIO_Label=Stepper1
PA7.Signal=GPIO_Output
PA8.GPIO_Label=Power
PA8.Signal=GPIO_Output
PB0.GPIO_Label=DIR2
PB0.Signal=GPIO_Output
PB1.GPIO_Label=Stepper2
PB1.Signal=GPIO_Output
PB10.GPIO_Label=Key1
PB10.Signal=GPIO_Input
PB11.GPIO_Label=Key2
PB11.Signal=GPIO_Input
PB12.GPIO_Label=Key3
PB12.Signal=GPIO_Input
PB13.Signal=SPI2_SCK
PB14.Signal=SPI2_MISO
PB15.Signal=SPI2_MOSI
PB2.GPIO_Label=CSN
PB2.Signal=GPIO_Output
PB3.Signal=USART2_TX
PB4.Signal=USART2_RX
PB6.GPIO_Label=IRQ
PB6.Signal=GPIO_Input
PB7.Signal=I2C1_SDA
PC13.GPIO_Label=LED
PC13.Signal=GPIO_Output
PF0-OSC_IN.Signal=RCC_OSC_IN
PF1-OSC_OUT.Signal=RCC_OSC_OUT

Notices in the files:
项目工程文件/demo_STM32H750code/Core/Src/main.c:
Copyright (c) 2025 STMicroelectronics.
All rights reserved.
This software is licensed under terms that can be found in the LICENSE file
